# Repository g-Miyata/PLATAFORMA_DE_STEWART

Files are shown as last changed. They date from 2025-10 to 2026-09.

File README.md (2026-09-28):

[REACT__BADGE]: https://img.shields.io/badge/react-%2320232a.svg?style=for-the-badge&logo=react&logoColor=%2361DAFB
[TS__BADGE]: https://img.shields.io/badge/typescript-%23007ACC.svg?style=for-the-badge&logo=typescript&logoColor=white
[THREE__BADGE]: https://img.shields.io/badge/three.js-000000?style=for-the-badge&logo=threedotjs&logoColor=white
[FastAPI__BADGE]: https://img.shields.io/badge/FastAPI-005571?style=for-the-badge&logo=fastapi
[TailwindCSS__BADGE]: https://img.shields.io/badge/tailwindcss-%2338B2AC.svg?style=for-the-badge&logo=tailwind-css&logoColor=white

<div align="center">

logo ifsp

<hr/>

<h1 align="center" style="font-weight: bold;">PLATAFORMA DE STEWART</h1>







</div>

## Visão Geral

Este repositório reúne o projeto da Plataforma de Stewart do IFSP (TCC 2025):

- **interface web** em React + Three.js (`interface/web`), com modelo 3D da bancada, tema claro/escuro e acessibilidade;
- **backend** FastAPI (`interface/backend`), que calcula a cinemática e conversa com o ESP32 pela serial;
- **firmwares** do ESP32-S3 (`esp32s3_codes`).

O backend também tem um **dispositivo virtual (simulador)**: dá para usar toda a interface e validar movimentos sem hardware.

## Arquitetura

```mermaid
flowchart LR
    subgraph Web ["Interface web (React)"]
        P["Páginas: Atuadores · Cinemática · Joystick<br>Rotinas · IMU · Ganhos PID<br>Simulador de voo · Orientação do avião"]
        V["Modelo 3D (React Three Fiber)"]
    end

    subgraph Backend ["Backend FastAPI :8001"]
        R["REST: /calculate, /apply_pose, /pid/*,<br>/motion/*, /emergency-stop ..."]
        W["WebSocket /ws/telemetry"]
        S["SerialManager"]
    end

    SIM["Simulador<br>(simulated_device.py)"]
    FW["ESP32-S3<br>pid-control-filter-spike-bno.ino"]
    IMU["Transmissor IMU<br>BNO085 / MPU-6050"]
    FG["FlightGear + fg-bridge.py"]

    Web -->|HTTP / WS| Backend
    S -->|porta COM| FW
    S -->|porta SIMULADOR| SIM
    IMU -->|ESP-NOW| FW
    FG -->|HTTP| Backend
```

## Executando

### Pré-requisitos

- **Python 3.12** oficial para Windows ([python.org](https://www.python.org/downloads/windows/)). A 3.12.10 é a última 3.12 com instalador para Windows. Na instalação, marque _Add python.exe to PATH_.
  - Cuidado com Pythons embutidos em outros programas (por exemplo o do Inkscape), que criam o ambiente virtual num formato incompatível. O `start.bat` detecta e recusa esses casos.
- **Node.js não é necessário** para usar a bancada: o build da interface (`interface/web/dist`) vem pronto no repositório. Só é preciso Node 24 para desenvolver o frontend.

### Iniciar

Na raiz do projeto:

```bat
start.bat
```

O script:

1. procura o Python 3.12 (primeiro `py -3.12`, depois `python`);
2. cria o ambiente virtual em `interface/backend/.venv` e instala as dependências;
3. sobe o FastAPI em `http://localhost:8001`;
4. abre a interface em **http://localhost:8001/**.

| Endereço | Conteúdo |
| --- | --- |
| http://localhost:8001/ | Interface nova (React) |
| http://localhost:8001/antigo/ | Interface antiga (HTML/JS), mantida durante a migração |
| http://localhost:8001/docs | Documentação interativa da API |

> Se aparecer "O ambiente virtual existente é inválido", apague a pasta `interface/backend/.venv` e rode o `start.bat` de novo.

### Pelo celular (rede local)

No PC, abra a tela **Celular** (menu ou botão no cabeçalho) e clique em **Ligar o modo rede**: o backend passa a atender também em **HTTPS 8443** na rede, sem reiniciar, e a tela mostra o QR code, o endereço (`https://<IP-do-PC>:8443/celular`) e o **PIN**. Para já abrir ligado:

```bat
start.bat rede
```

- Com `start.bat rede`, o backend escuta na rede em **HTTP 8001** e **HTTPS 8443**, no mesmo processo (`interface/backend/serve.py`). O HTTPS usa um certificado autoassinado gerado na primeira vez em `interface/backend/certs/`, e é ele que libera o giroscópio do celular (os navegadores só dão o sensor em HTTPS).
- No celular, aceite uma vez o aviso de certificado e digite o PIN. **Um celular por vez:** com um já conectado, o PC mostra qual é (aparelho, IP, há quanto tempo) e o botão para desconectá-lo; um segundo celular vê o aviso e só entra depois. No celular, **Desconectar** (no topo) libera a vez. O PC também mostra quem abriu a página e está esperando o PIN, e pode gerar outro PIN.
- Sem o PIN, o celular só acompanha. O botão **PARAR** funciona sempre, em qualquer aparelho. O próprio PC nunca pede PIN. Um IP que erra o PIN 5 vezes fica bloqueado por um minuto.
- A tela `/celular` tem **giroscópio** (incline o celular e o tampo acompanha, com zerar, sensibilidade e iniciar/parar), **joystick na tela** (dois sticks, Z e yaw) e **Bancada 3D por toque** (P1–P6 ou tampo, − / + que repetem ao segurar, desfazer e ao vivo). O controle para sozinho se a tela apagar, se o sensor parar ou numa parada de emergência.
- **Firewall:** na primeira vez, o Windows pergunta se libera o Python; permita em **redes privadas**. Para liberar à mão, num prompt de administrador:
  `netsh advfirewall firewall add rule name="Plataforma de Stewart" dir=in action=allow protocol=TCP localport=8001,8443 profile=private`

## Modo simulação (sem hardware)

No topo da interface, escolha **Simulador** e clique em **Conectar**. O selo muda para **SIMULAÇÃO** (azul). Nada físico se move, e todas as páginas funcionam.

- O backend passa a usar `interface/backend/simulated_device.py` no lugar da porta serial. Ele aceita os mesmos comandos do firmware (`spmm6x=`, `sel=`, `kpmm=`, `A`/`R`/`OK`...), roda o mesmo PID e responde com a mesma telemetria CSV.
- A dinâmica de cada atuador (velocidade máxima e zona morta) foi ajustada aos ensaios de degrau reais (`MATLAB/workspace1-6.mat`) por `interface/backend/tools/fit_sim_params.py`, com fit de ~90%. Os parâmetros ficam em `interface/backend/sim_params.json`.
- No modelo 3D, a plataforma sólida é a medida (telemetria) e o **fantasma verde** é a pose comandada. A diferença entre as duas mostra o atraso real dos atuadores.
- A página **Rotinas** estima a velocidade de pico que cada movimento exige e avisa quando ela passa do que os atuadores sustentam (~12 mm/s).
- Nas páginas Joystick e IMU há controles virtuais (sliders) para quando não há gamepad ou sensor.
- A **Bancada 3D** (`/bancada-3d`) traz o modelo mais detalhado, com tela cheia. Clique num pistão e arraste a seta para mudar só o comprimento dele: os outros cinco ficam fixos e o tampo se acomoda pela cinemática direta. Clique no ponto verde do tampo para mover a plataforma inteira em Z, roll, pitch ou yaw. Tudo também funciona pelo teclado.

Para usar o hardware, selecione a porta COM do ESP32-S3 e confirme. O selo fica vermelho, **HARDWARE REAL**.

### Criar, ensinar e analisar

Além das páginas de controle, o menu tem:

| Página | O que faz |
| --- | --- |
| **Gravar e reproduzir** (`/gravar`) | Tudo na própria página: **ponto a ponto** (posicione a plataforma na Bancada 3D embutida ou pelos valores e grave o ponto; a rotina liga os pontos) ou **ao vivo** (dirija com os joysticks da tela ou um gamepad e grave o movimento). Vira poses-chave numa linha do tempo com interpolação suave, prévia no modelo e reprodução na plataforma (`POST /motion/trajectory`, 60 Hz). Confere curso e velocidade antes de mover. |
| **Programação em blocos** (`/blocos`) | Blocos no estilo Scratch (Blockly): mover para, mover eixo, esperar, repetir, rotinas prontas. O programa vira uma trajetória, com a lista de passos em texto. |
| **Apresentação** (`/apresentacao`) | Tela para feiras e exposições, em página inteira (tema escuro ou claro, pelo botão no canto). Mostra um show automático de 6 cenas (título, 6 graus de liberdade, pistões ao vivo, simulador de voo, cinemática) e quem toca na tela ou mexe no gamepad assume o controle, voltando ao show após 30 s. A bancada física só se move pelo **painel do operador** (tecla **O** ou segurar o logo): quiosque com amplitude e velocidade limitadas, controle do público na bancada (até 5°) e tempo de sessão. No painel também dá para trocar o show pelo **Simulador de voo**: um voo gravado do ERJ145 toca em laço pelo motion cueing (washout), com instrumentos na tela, a imagem do FlightGear no canto quando ele está aberto e, se o operador ligar, a bancada engatada no cueing. `?cena=voo` abre direto numa cena e `?modo=voo` no simulador de voo. |
| **Aula de cinemática** (`/aula`) | Curso em dois módulos, na notação do TCC (aᵢ, bᵢ, p, R, Lᵢ = ‖p + R·bᵢ − aᵢ‖). **Conhecendo a Plataforma**: peças, história, 6 GDL, atuadores e juntas, referenciais {B} e {P}. **Cinemática**: seriais × paralelos com um braço UR5e (cadeia DH e as até 8 soluções da inversa) e um braço 2R, pose e matrizes com números ao vivo, inversa passo a passo e direta com experimento, esferas de restrição e as iterações do solver. Tem perguntas rápidas e o progresso fica salvo. **Modo aula** (tecla F): tela cheia para projetar, com texto e modelo maiores; ←/→ passam as etapas. |
| **Jogo da bolinha** (`/jogo`) | Incline o tampo e leve a bolinha ao alvo, em 5 fases. Pode espelhar na plataforma (até 5°, devagar). |
| **Espaço de trabalho** (`/espaco-de-trabalho`) | Volume que o centro do tampo alcança com os limites reais, corte colorido pelo limite que está mais perto (curso, cardã da base, cardã do tampo ou folga entre pernas), inclinação máxima por direção e alcance de cada eixo com e sem margem. |
| **Limites da mecânica** (Ajustes → `/limites`) | Os valores físicos de `interface/backend/limits.json` (curso de 500 a 750 mm, ângulo máximo dos cardãs, raio e folga das pernas) e a margem de operação (20%), com o alcance que resulta. Tudo o que comanda a bancada deriva daqui. |
| **Laboratório: calço do cardã** (`/laboratorio/calco`, fora do menu) | Simula um calço inclinado embaixo de cada cardã do tampo: compara o alcance com a montagem de hoje, testa poses, mostra a peça em 3D e baixa o STL do calço e da arruela inclinada, com o passo a passo de montagem. É só simulação: não muda os limites da bancada. |
| **Calibração** (Ajustes → `/calibracao`) | Um processo de 3 a 4 min que interrompe o que estiver rodando e faz o **autoteste** (cada pistão sozinho ±30 mm em torno do home: velocidade, atraso, erro final e ruído; aponta travado, invertido, lento ou ruidoso) e a **recalibração** do simulador (gêmeo digital: um simulador "sombra" recebe os mesmos comandos só durante a calibração; o ajuste de vmax e zona morta só entra se melhorar a reprodução). Gera um relatório datado, comparado com o anterior; os parâmetros novos vão para o `sim_params.json` (com cópia `.bak`) só se você aplicar. Também compara ensaios CSV das Rotinas com o simulador. |
| **Simulador de voo** (`/simulador-voo`) | Sensações do voo no FlightGear com washout clássico (inclinação sustentada, translação e rotação), respeitando curso e velocidade dos pistões, com o ERJ145 do IFSP voando no FlightGear dentro da página. Toca voos gravados (inclui uma rotina pronta), grava voos ao vivo via UDP e compara avião × plataforma. Veja [MOTION-CUEING-README.md](MOTION-CUEING-README.md) e [FLIGHTGEAR-SETUP.md](FLIGHTGEAR-SETUP.md). |
| **Orientação do avião** (`/orientacao-voo`) | A plataforma copia roll e pitch do avião (até ±12°), ao vivo ou de um voo gravado, com o mesmo FlightGear embutido. |

Enquanto uma rotina ou trajetória roda, o backend recusa comandos manuais (409), para que eles não briguem com o movimento. Durante a calibração, recusa qualquer comando (poses, rotinas, PID, console).

### Segurança

- **Parar** (ou a tecla **Esc**) chama `POST /emergency-stop`: interrompe rotinas e a simulação de voo, tira o firmware do modo manual (`OK`) e congela os atuadores na posição atual. Joystick, IMU e "aplicar automaticamente" desligam sozinhos.
- **Limites reais** (`interface/backend/limits.py`, igual no frontend em `lib/limits.ts`): uma pose só é aceita se, com **20% de margem**, cada perna ficar no curso (525 a 725 mm dos 500 a 750 mm do atuador), os cardãs da base e do tampo não passarem de 80% do ângulo máximo e duas pernas não chegarem perto demais. O ângulo máximo dos cardãs (45°) é de catálogo: a junta real (o cardã metálico no topo e na base de cada perna, preso ao suporte azul impresso) não foi medida (o modelo 3D do cardã daria só 17°, menos do que a bancada já faz; veja `tools/estimate_cardan_limit.py`). Meça e ajuste em **Ajustes → Limites da mecânica**. O home fica no meio do curso de operação (570 mm). Sliders, joystick, IMU, rotinas, trajetórias, setpoints manuais e o simulador de voo usam esse envelope, em vez de faixas fixas.
- O backend escuta só em `127.0.0.1`, e o CORS é restrito ao próprio servidor e ao servidor de desenvolvimento. No modo rede (`start.bat rede`), escuta na rede e exige o PIN para comandos que vêm de outros aparelhos.

## Desenvolvimento

### Backend

```bat
cd interface\backend
.venv\Scripts\activate
pip install -r requirements.txt pytest
uvicorn app:app --reload --port 8001
pytest
```

Os testes automatizados ficam em `interface/backend/tests/` e cobrem a cinemática, o simulador e a API com o simulador conectado. Os `test_*.py` soltos na pasta do backend são scripts manuais antigos (precisam de servidor ou hardware) e o `pytest.ini` os ignora.

### Frontend (`interface/web`)

```bat
cd interface\web
npm install
npm run dev
```

O servidor de desenvolvimento fica em http://localhost:5173 e repassa a API para o backend em `:8001`.

| Comando | O que faz |
| --- | --- |
| `npm run build` | Gera `dist/`, que o FastAPI serve. **Rode antes de commitar** mudanças no frontend. |
| `npm run lint` / `npm run typecheck` | ESLint (inclui regras de acessibilidade jsx-a11y) e TypeScript |
| `npm test` | Testes unitários (Vitest) |
| `npm run test:e2e` | Playwright + axe contra o build, com o simulador (usa o Edge instalado no Windows)  |

Detalhes de arquitetura, tema IFSP, acessibilidade e o fluxo para melhorar o modelo 3D no Blender estão em [interface/web/README.md](interface/web/README.md).

### Integração contínua

`.github/workflows/ci.yml` roda pytest, lint, tipos, testes, build e os testes de ponta a ponta com acessibilidade em cada PR. Em tags `v*`, anexa o build (`stewart-web-dist.zip`) à release.

### Firmware ESP32-S3

- **Arduino IDE 2.x**, com o core _esp32 by Espressif Systems_ **2.0.x** (testado na 2.0.15). O core 3.x muda `ledcSetup`/`ledcAttachPin` e o callback do ESP-NOW, e o código não compila nele.
- **Bibliotecas:** SparkFun BNO08x Cortex Based IMU 1.0.6 e MPU6050_light.
- **Driver USB-serial:** CP210x ([tutorial Robocore](https://www.robocore.net/tutoriais/instalando-driver-do-nodemcu)).

| Sketch | Função |
| --- | --- |
| `esp32s3_codes/stewart-platform-control/pid-control-filter-spike-bno/` | Firmware principal: PID dos 6 atuadores, telemetria, receptor ESP-NOW |
| `esp32s3_codes/stewart-platform-control/BNO085/` | Transmissor de orientação com BNO085 |
| `esp32s3_codes/stewart-platform-control/mpu-6050/` | Transmissor de orientação com MPU-6050 |
| `esp32s3_codes/others/` | Sketches de teste antigos (algumas pinagens diferem da principal: não gravar sem conferir) |

Comandos seriais e telemetria: [PID-CONTROL-FILTER-SPIKE-BNO.md](PID-CONTROL-FILTER-SPIKE-BNO.md).

## Estrutura do repositório

| Pasta | Conteúdo |
| --- | --- |
| `interface/web` | Interface React (código em `src/`, build em `dist/`) |
| `interface/backend` | FastAPI, simulador, testes (`tests/`) e ferramentas (`tools/`) |
| `interface/frontend` | Interface antiga (servida em `/antigo/` até o fim da migração) |
| `interface/simulation` | Ponte FlightGear (`fg-bridge.py`), motion cueing e voos gravados |
| `interface/mcp-flightgear`  | Servidor MCP para ler e controlar o FlightGear pelo Claude |
| `interface-coleta-de-dados` | Aplicativos Python usados nas aquisições do TCC |
| `esp32s3_codes` | Firmwares do ESP32-S3 |
| `MATLAB` | Identificação de sistema e projeto dos controladores |
| `aquisições` | Dados brutos dos ensaios (CSV) por pistão |
| `3D-drawings-archives` | Peças para impressão 3D (STL/3MF) |
| `docs` | Monografia, apresentação e cópias em PDF da documentação |

## Documentação por módulo

Os documentos abaixo descrevem a **interface antiga** (em `/antigo/`) e os endpoints, que continuam os mesmos:

- [JOYSTICK-CONTROL-README.md](JOYSTICK-CONTROL-README.md) e [CONTROLLER-README.md](CONTROLLER-README.md): joystick e `/joystick/pose`
- [KINEMATICS-README.md](KINEMATICS-README.md): cinemática, `/calculate` e `/apply_pose`
- [ACCELEROMETER-README.md](ACCELEROMETER-README.md): controle por IMU e `/mpu/control`
- [ROUTINES-README.md](ROUTINES-README.md): rotinas e `/motion/*`
- [ACTUATORS-README.md](ACTUATORS-README.md): telemetria, setpoints e comandos manuais
- [SETTINGS-README.md](SETTINGS-README.md): `/pid/gains` e `/pid/settings`
- [FLIGHTGEAR-README.md](FLIGHTGEAR-README.md): ponte antiga roll/pitch via Telnet (interface `/antigo`)
- [interface/mcp-flightgear/README.md](interface/mcp-flightgear/README.md): servidor MCP do FlightGear
- [MOTION-CUEING-README.md](MOTION-CUEING-README.md): Simulador de voo e Orientação do avião, voos gravados e ponte UDP
- [FLIGHTGEAR-SETUP.md](FLIGHTGEAR-SETUP.md): instalar FlightGear, FGData e ERJ145, rodar no FlightGear e erros comuns
- Firmware: [PID-CONTROL-FILTER-SPIKE-BNO.md](PID-CONTROL-FILTER-SPIKE-BNO.md), [BNO085-README.md](BNO085-README.md), [MPU6050-README.md](MPU6050-README.md)

## Versionamento

A branch padrão é `main`. Use uma branch por mudança (`feat/...`, `fix/...`, `docs/...`) e abra um Pull Request: o CI precisa passar antes do merge.

### Autor

**Guilherme Miyata** - Instituto Federal de São Paulo (IFSP)
Trabalho de Conclusão de Curso - 2025

---

<a href='https://github.com/g-Miyata'>Github</a><br>
<a href='https://www.linkedin.com/in/g-miyata'>Linkedin</a><br>
<a href='https://www.g-miyata.com'>Portfólio</a>

**Última atualização:** Setembro 2026

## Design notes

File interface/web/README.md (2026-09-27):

# Interface web (React)

Frontend da Plataforma de Stewart: React 19 + TypeScript + Vite, Tailwind CSS v4, Radix UI, React Three Fiber (three.js) e Chart.js. O build (`dist/`) é servido pelo próprio FastAPI em `http://localhost:8001/`; não há dependência de CDN, então a interface funciona offline.

## Rodando

```bat
npm install
npm run dev        :: http://localhost:5173 (a API é repassada para o backend em :8001)
npm run build      :: gera dist/, servido pelo FastAPI. Rode antes de commitar.
npm run lint       :: ESLint + regras de acessibilidade (jsx-a11y) + regras do React Compiler
npm run typecheck
npm test           :: Vitest (cinemática, rotinas, joystick, CSV...)
npm run test:e2e   :: Playwright + axe contra o build, com o simulador
```

Equações em **KaTeX** (empacotado, funciona offline; `components/Tex.tsx`).

**Limites reais:** `lib/limits.ts` faz as mesmas checagens do backend (curso de operação, cardãs e folga entre pernas); `limits.test.ts` confere contra `limits.fixture.json`, gerado por `interface/backend/tools/make_limits_fixture.py` (rode de novo se mudar `limits.py`). `useLimits()` dá o alcance de cada eixo para sliders e controles.

O `test:e2e` usa o Edge instalado no Windows. Com o `start.bat` aberto, rode num backend separado (`PW_PORT=8011`) para não desconectar a sua sessão. Defina `PYTHON` com o Python do venv do backend se ele não for o `python` do PATH. No CI (Linux), use `PW_CHANNEL=chromium` depois de `npx playwright install chromium`.

## Estrutura

```
src/
  app/          App (rotas), AppShell (cabeçalho, menu, selo de modo), providers, nav
  components/   ui/ (Button, Card, campos, status), charts/LiveChart, PageLayout (PageHeader, WithViewer)
  features/
    platform3d/ modelo 3D: PlatformViewer, Scene, Actuators, TopPlate, BaseFrame, GhostPlatform,
                BlueMount (STL real), ModelSlot (modelos .glb do Blender), sceneState (SceneStore)
    control/    PoseEditor, validação no backend, trava de controle ao vivo
    serial/     conexão (hardware real pede confirmação; padrão = simulador)
    safety/     parada de emergência (botão e tecla Esc)
    bench3d/    Bancada 3D: store de edição (FK ao mexer num pistão, IK ao mexer na pose),
                gizmos de arraste (seta de eixo, anéis de rotação) e cena premium
    joystick/   Gamepad API + mapeamento idêntico ao /joystick/pose
    routines/   presets, estimativa de velocidade, status e gráfico comandado × medido
    recorder/   trajetórias (interpolação, simplificação, viabilidade), gravador global e biblioteca
    blocks/     blocos do Blockly e compilador (JSON do Blockly → poses-chave)
    presentation/ tela de exposição: laço de cenas, palco (bloom, reflexo), controle do público,
                painel do operador e quiosque (lista segura de movimentos)
    lesson/     aula: currículo (curriculum.ts), widgets, sobreposições 3D e o UR5e (serial/)
    game/       física da bolinha (passo fixo de 120 Hz), fases e cena
    workspace/  varredura do espaço de trabalho (Web Worker) e iso-superfície
    calibration/ calibração (status, indicador no cabeçalho, relatório)
    twin/       gêmeo digital: gráfico real × simulado, métricas e comparação de ensaio CSV
    actuators/  console serial
  lib/          api (REST tipado), ws (WebSocket único com backoff), kinematics (inversa),
                forwardKinematics (direta, Levenberg-Marquardt), types, csv
  stores/       zustand: connection, telemetry, ui (tema, contador de parada de emergência)
  pages/        uma página por rota
```

### Fluxo de dados

- **Um WebSocket só** (`lib/ws.ts`), aberto na raiz do app. Como é uma SPA, ele sobrevive à troca de páginas. As mensagens vão para `stores/telemetry.ts` (`telemetry`, `motion_tick`, `raw`).
- **REST** em `lib/api.ts`, sempre na mesma origem. O estado da serial é consultado a cada 2 s (`features/serial/status.ts`) e alimenta o selo **SIMULAÇÃO / HARDWARE REAL / DESCONECTADO / BACKEND OFFLINE**.
- **Dados de alta frequência não passam pelo React**: gráficos (`LiveChart`) e o 3D (`SceneStore`) assinam o store diretamente e se atualizam de forma imperativa. Tabelas e textos usam `useThrottledTelemetry` (5 a 10 Hz).
- **Cinemática no navegador serve só para desenhar** (`lib/kinematics.ts`, mesmas fórmulas de `app.py`, com teste contra valores gerados pelo backend). Validar e aplicar uma pose é sempre papel do backend.

### Modelo 3D

`PlatformViewer` mostra duas plataformas:

- **sólida**: a pose medida (`pose_live` da telemetria; com o simulador, é o modelo virtual). Sem telemetria, mostra a pose prevista.
- **fantasma verde**: a pose comandada/prevista pela página (sliders, joystick, IMU, rotina). Só aparece quando difere da medida.

Cada atuador acende em âmbar perto do batente e em vermelho fora do curso. As mesmas informações estão na tabela abaixo do canvas, que é a alternativa textual do 3D. O eixo Z aponta para cima e as unidades são mm, iguais às do backend.

Tudo é montado a partir da geometria do `GET /config` (`base_points`, `platform_points_local`, curso), com fallback embutido em `features/platform3d/geometry.ts`. Mudou a geometria no backend, o desenho acompanha.

### Bancada 3D

O modelo "premium" (`features/platform3d/premium/`) é usado só nesta tela:

- **Peças:** tubo de alumínio de cantos arredondados, motor com etiqueta e o número do pistão, caixa de redução, juntas cardã cromadas, perfis 40×40 com canais em T e a parte elétrica (fonte, drivers, canaletas, trilho DIN, botão de emergência).
- **Render:** pós-processamento (N8AO, bloom, AgX, SMAA) no modo **Alta**. O modo **Leve** entra sozinho se o FPS cair.
- **Frameloop sob demanda:** a cena só redesenha quando a edição, a telemetria ou a câmera mudam.

**Teclado** (com o modelo em foco):

| Tecla | Ação |
| --- | --- |
| 1 a 6 | seleciona um pistão |
| C | seleciona o tampo e alterna o eixo |
| Z, R, P, Y | escolhe altura, roll, pitch ou yaw |
| setas | ajustam (Shift ×10) |
| Ctrl+Z | desfaz |
| F | tela cheia |

## Tema IFSP e acessibilidade

- **Tokens** em `src/index.css`, para `[data-theme="light"]` e `[data-theme="dark"]`. O verde (#2F9E41) e o vermelho (#CD191E) institucionais são usados em ícones, bordas e superfícies. Para texto, o tema claro usa um verde escurecido (#1B6E2B) e o escuro um verde claro, para passar o contraste AA.
- **Escolha do tema:** o padrão segue o sistema; o botão no cabeçalho alterna e salva em `localStorage`. Um script inline em `index.html` aplica o tema antes da primeira pintura.
- **Meta: WCAG 2.1 AA.** O `npm run test:e2e` roda o axe em todas as páginas, nos dois temas, e falha em violações sérias ou críticas.
- **Regras seguidas nos componentes:**
  - todo controle tem rótulo;
  - sliders com `aria-valuetext` em pt-BR ("5,5 graus") e campo numérico ao lado;
  - estado nunca só por cor (ícone + texto);
  - link "Pular para o conteúdo";
  - o foco vai para o conteúdo ao trocar de página;
  - atalho **Esc** para a parada de emergência;
  - `prefers-reduced-motion` desliga animações e a suavização do 3D.

## Modelos 3D (Blender)

A carcaça dos atuadores, os cardãs e a parte elétrica da bandeja (drivers, fonte, disjuntor, réguas de bornes, DB37 e botoeira de emergência) vêm de `.glb` gerados por scripts do Blender em [`3D-drawings-archives/blender/`](../../3D-drawings-archives/blender/README.md). O braço UR5e da aula vem do MuJoCo Menagerie (BSD-3-Clause, licença em `public/models/serial/LICENSE-ur5e.txt`), convertido por `ur5e.py`. O resto é gerado no código (procedural), com proporções tiradas das fotos da bancada. O bloco azul da base usa a peça real do repositório (`3D-drawings-archives/kardan-joint/kardan-joint.stl`, copiada para `public/models/`).

Para trocar uma peça por um modelo mais detalhado feito no Blender:

1. **Unidades:** em *Scene Properties > Units*, use *Unit Scale* 0,001 e *Length* em milímetros, para que **1 unidade = 1 mm**.
2. **Eixos e origem** (o exportador glTF converte o Z do Blender no +Y do three.js, que é o eixo do atuador no código):

   | Nome do arquivo | Origem (0,0,0) | Eixo do Blender +Z | +X |
   | --- | --- | --- | --- |
   | `actuator-housing.glb` | centro da junta da base | ao longo do atuador; a carcaça vai de ~32 a ~330 mm | lado do motor (para fora da plataforma) |
   | `actuator-rod.glb` | centro da haste | ao longo da haste (400 mm de comprimento) | livre |
   | `kardan-top.glb` | centro da junta superior | ao longo da perna | livre |

3. **Materiais:** Principled BSDF (vira PBR no glTF). Alumínio fosco, cromo para a haste, texturas de até 1024 px. Não é preciso pintar a cor de cada pistão: a faixa colorida continua sendo desenhada pelo código.
4. **Exportar:** *File > Export > glTF 2.0*, formato **.glb**, *Selected Objects*, *+Y Up* ligado, *Apply Modifiers*, sem câmeras, luzes ou animações.
5. **Otimizar** (Meshopt; não use Draco, que precisaria de CDN):

   ```bat
   npx @gltf-transform/cli optimize actuator-housing.glb public/models/actuator-housing.glb --compress meshopt --texture-compress webp
   ```

6. **Registrar** o nome em `public/models/manifest.json` (ex.: `"models": ["actuator-housing"]`) e rodar `npm run build`.

Se o arquivo faltar ou não carregar, a peça procedural volta sozinha (`ModelSlot`). Para conferir a escala, a carcaça precisa ter ~330 unidades no eixo do atuador. Se vier 0,33, a unidade estava em metros.

**Referências visuais:** fotos da bancada e Figuras 17, 20, 21 e 27 da monografia (`docs/TCC_Guilherme_rev4_final.docx`).

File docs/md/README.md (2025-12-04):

[JAVASCRIPT__BADGE]: https://img.shields.io/badge/JavaScript-000?style=for-the-badge&logo=javascript
[CSS3__BADGE]: https://img.shields.io/badge/CSS3-%231572B6.svg?style=for-the-badge&logo=css3&logoColor=white
[FastAPI__BADGE]: https://img.shields.io/badge/FastAPI-005571?style=for-the-badge&logo=fastapi
[TailwindCSS__BADGE]: https://img.shields.io/badge/tailwindcss-%2338B2AC.svg?style=for-the-badge&logo=tailwind-css&logoColor=white
[HTML5__BADGE]: https://img.shields.io/badge/html5-%23E34F26.svg?style=for-the-badge&logo=html5&logoColor=white

<div align="center">

logo ifsp

<hr/>

<h1 align="center" style="font-weight: bold;">PLATAFORMA DE STEWART</h1>







</div>

## Visão Geral

Esta documentação consolida o ecossistema do projeto da Plataforma de Stewart (IFSP – TCC 2025), abrangendo o **frontend** (interfaces web em Three.js/Vanilla), o **backend** (FastAPI + Serial) e os **firmwares** do ESP32-S3. Abaixo você encontrará uma visão macro dos módulos, instruções de instalação/execução e um guia de versionamento, além de links para documentação detalhada de cada funcionalidade.

## Arquitetura Macro

```mermaid

flowchart TB
    subgraph Frontend ["FRONTEND"]
        F1[controller.html] --> F2[joystick.html] --> F3[kinematics.html] --> F4[accelerometer.html] --> F5[routines.html] --> F6[actuators.html] --> F7[settings.html]
    end

    subgraph Backend ["BACKEND"]
        B1["Endpoints REST<br>/apply_pose, /calculate,<br>/pid/*, /motion/*"]
        B2["WebSocket /ws/telemetry"]
        B3["Serial Manager<br>(pyserial)"]
    end

    subgraph Firmware ["ESP32-S3"]
        FW1["PID controle 6 DOF<br>pid-control-filter-spike-bno.ino"]
        FW2["Transmissor BNO085<br>BNO085.ino"]
        FW3["Transmissor MPU6050<br>cmpu-6050.ino"]
    end

    IMU["IMU remota<br>(BNO085 OU MPU6050)"]

    Frontend -->|HTTP/WS| Backend
    Backend -->|Serial USB| FW1
    FW1 --> Backend

    FW2 --> IMU
    FW3 --> IMU
    IMU -->|ESP-NOW| FW1

```

# Iniciando

## Instalação

### Pré-requisitos

#### Versão do Python

- Python **3.12.17**

#### Dependências Python

As bibliotecas do backend estão em `interface/backend/requirements.txt`. Instale-as com:

```bash
pip install -r requirements.txt
```

Conteúdo atual:

```
# ==== API e servidor Web  ====
fastapi==0.104.1
starlette==0.27.0
uvicorn[standard]==0.24.0.post1
pydantic==2.5.3
python-multipart==0.0.9

# ==== Científico ====
numpy==1.26.4
scipy==1.13.1

# ==== Serial ====
pyserial==3.5

# ==== Utilitários ====
python-dotenv==1.0.1
typing-extensions>=4.8,<5
```

#### Ambiente ESP32-S3/ESP32

- **Arduino IDE 2.x**
- **Core ESP32**: _esp32 by Espressif Systems_ v2.0.15
- **Bibliotecas adicionais**:
  - SparkFun BNO08x Cortex Based IMU – v1.0.6
- **Driver USB–Serial**: CP210x USB to UART Bridge  
  Download e instruções: [Robocore – Instalando driver do NodeMCU](https://www.robocore.net/tutoriais/instalando-driver-do-nodemcu)

#### Outros

- **Node.js** LTS (para rodar servers estáticos, bundlers opcionais etc.).
- **Ferramentas de linha de comando**: `git`, `make` (opcional), `python -m http.server` ou similar para servir o frontend.

### Backend (FastAPI)

1. Entre em `interface/backend`.
2. Crie (opcional) um ambiente virtual e instale dependências:
   ```bash
   python -m venv .venv
   source .venv/bin/activate  # Linux/macOS
   .\.venv\Scripts\activate   # Windows PowerShell
   pip install -r requirements.txt
   ```
3. Execute o servidor:
   ```bash
   uvicorn app:app --reload --host 0.0.0.0 --port 8001
   ```
4. Confirme que a API responde em `http://localhost:8001/docs`.

### Frontend

O frontend é estático. Basta abrir os arquivos `.html` diretamente no navegador ou servir via um servidor local (ex.: `live-server`, `python -m http.server`, etc.). Para páginas que dependem de módulos ES6, verifique se o navegador carrega via `file://` sem bloquear. Recomenda-se rodar um server simples:

```bash
cd interface/frontend
python -m http.server 8080
# Abrir http://localhost:8080/controller.html
```

> Existe também um script pronto (`start.bat`) na raiz do repositório. Ele abre duas janelas de terminal: uma com o backend FastAPI (`uvicorn`) e outra com `python -m http.server 8080` para o frontend. Basta executar `start.bat` para subir ambos.

### Firmware ESP32-S3

1. Abra `esp32s3_codes/pid-control-filter-spike-bno/pid-control-filter-spike-bno.ino` (ou variantes) no Arduino IDE (ESP32 S3 board selecionada) ou PlatformIO.
2. Ajuste as constantes de pinagem/ganhos conforme necessário.
3. Compile e faça upload via USB.

> Consulte [PID-CONTROL-FILTER-SPIKE-BNO.md](PID-CONTROL-FILTER-SPIKE-BNO.md) para detalhes completos do firmware.

## Execução e Fluxo

1. **Ligar o ESP32-S3** com o firmware PID. Ele aguardará setpoints pela serial e telemetria pelo sensor.
2. **Iniciar o backend** (`uvicorn app:app --reload --port 8001`).
3. **Abrir uma página do frontend**:
   - `joystick.html` para controle via joystick.
   - `kinematics.html` para cálculos de cinemática.
   - `accelerometer.html` para controle por IMU.
   - `routines.html` para rotinas de movimentoBN e gráficos.
   - `actuators.html` para controle PID e telemetria.
   - `settings.html` para ajustes rápidos de ganhos/offsets.
4. Conectar-se à porta serial na UI e ativar as funcionalidades desejadas.

## Documentação por Módulo

- **Controle por Joystick (controller/joystick)**  
  [JOYSTICK-CONTROL-README.md](JOYSTICK-CONTROL-README.md) – explica endpoints (`/joystick/pose`), mapeamentos dos eixos, telemetria, segurança e UI.
- **Cinemática (kinematics.html + kinematics.js)**  
  [KINEMATICS-README.md](KINEMATICS-README.md) – descreve o preview 3D, inputs e integração com `/calculate` e `/apply_pose`.
- **Controle por Acelerômetro**  
  [ACCELEROMETER-README.md](ACCELEROMETER-README.md) – modo roll/pitch/yaw via IMU (MPU/BNO), WebSocket de telemetria, recalibração e comandos `/mpu/control`.
- **Rotinas de Movimento**  
  [ROUTINES-README.md](ROUTINES-README.md) – presets, Chart.js, IndexedDB para gravação, endpoints `/motion/*`.
- **Painel de Atuadores / PID**  
  [ACTUATORS-README.md](ACTUATORS-README.md) – telemetria, setpoints, comandos manuais, export CSV, integração com `/pid/*`.
- **Painel de Configurações**  
  [SETTINGS-README.md](SETTINGS-README.md) - explica como ler/aplicar `kp/ki/kd`, deadband, PWM mínimo via `/pid/gains` e `/pid/settings`.
- **Integração FlightGear**  
  [FLIGHTGEAR-README.md](FLIGHTGEAR-README.md) - ponte Telnet->FastAPI que lê roll/pitch do simulador, valida com `/calculate`, publica pré-visualização e envia poses seguras via `/apply_pose`.
- **Firmware ESP32-S3**
  - [PID-CONTROL-FILTER-SPIKE-BNO.md](PID-CONTROL-FILTER-SPIKE-BNO.md) – loop PID principal no ESP32-S3.
  - [BNO085-README.md](BNO085-README.md) – transmissor ESP-NOW baseado no sensor SparkFun BNO08x (Euler + quaternions).
  - [MPU6050-README.md](MPU6050-README.md) – transmissor ESP-NOW com MPU-6050 (roll/pitch/yaw simples).

## Código do ESP32-S3

O código principal está em `esp32s3_codes/pid-control-filter-spike-bno/`. Ele implementa:

- **ESP-NOW** para receber dados do sensor de orientação (MPU6050 ou BNO085) e gravar MAC para comandos de retorno.
- **Controle PID** com feedforward e anti-windup.
- **Parser serial** para receber setpoints e ajustes vindos do backend (comandos `spmm6x`, `kpmm`, `u0a`, `offset`, etc.).
- **Telemetria** no formato CSV, compatível com gráficos no frontend (`actuators.html`).

> Transmissores auxiliares:
>
> - [BNO085-README.md](BNO085-README.md) - leitura do SparkFun BNO08x (Euler + quaternions) e envio por ESP-NOW.
> - [MPU6050-README.md](MPU6050-README.md) - versão simplificada usando MPU6050_light.

### Principais integrações com o backend

- `apply_setpoint_all` e `apply_setpoint_individual` são acionados via `/apply_pose` (controller/joystick).
- `set_pid_gains`, `set_pid_offset`, `set_pid_feedforward` são usados pelas páginas `settings` e `actuators`.
- Comandos manuais (`man=adv`, `man=ret`, `man=free`) são expostos no painel de atuadores para testes de bancada.

## Versionamento

O repositório utiliza Git (branch padrão `docs/atualiza-documentacao`). Recomenda-se o seguinte fluxo:

1. **Commits frequentes** por feature:
   - `feature/frontend-joystick-z-trigger`
   - `feature/backend-motion-endpoints`
   - `docs/add-accelerometer-readme`
2. **Pull Requests** para revisão (incluir referência a issues do Trello/Jira).
3. **Tags** para releases estáveis:
   - `v1.0.0` – primeiro release funcional (controle manual + PID).
   - `v1.1.0` – inclui modos de rotinas, telemetria e joystick Z-trigger.
4. **Changelogs** no README ou em `CHANGELOG.md`.

### Autor

**Guilherme Miyata** - Instituto Federal de São Paulo (IFSP)  
Trabalho de Conclusão de Curso - 2025

---

<a href='https://github.com/g-Miyata'>Github</a><br>
<a href='www.linkedin.com/in/g-miyata'>Linkedin</a><br>
<a href='https://www.g-miyata.com'>Portfólio</a>

**Última atualização:** Novembro 2025

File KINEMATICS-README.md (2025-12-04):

# Sistema de Cinemática & Telemetria - Plataforma de Stewart

## Visão Geral

Interface completa para montar poses, visualizar o resultado em 3D e acompanhar a plataforma física em tempo real. A página `kinematics.html`, apoiada pelo script `kinematics.js`, conversa com o backend FastAPI (`app.py`) para calcular cinemática inversa, validar limites e enviar comandos via serial.

## Características

- Controle manual da pose com inputs numéricos e sliders sincronizados para X/Y/Z (±60 mm, Z 400–600 mm) e Roll/Pitch/Yaw (±25°).
- Pré-visualização 3D instantânea no `canvas-preview`, renderizada a partir da resposta do endpoint `/calculate`.
- Painel live (`canvas-live`) que replica a pose real recebida por WebSocket e mostra o comprimento de cada atuador.
- Monitoramento do IMU/MPU com leitura de Roll, Pitch, Yaw e quaternion formatado quando enviado pelo BNO085.
- Botão “Aplicar na Bancada” condicionado à validade do cálculo; dispara `/apply_pose` e envia `spmm6x=...` para o ESP32.
- Ações auxiliares: reset rápido, recalibração do MPU, indicadores de erro/toast e watchdog para telemetria.

## Arquitetura

### Backend (`interface/backend/app.py`)

- **`POST /calculate`**: recebe `PoseInput`, executa `platform.inverse_kinematics`, calcula percentuais de curso e devolve `PlatformResponse` com `actuators`, `base_points`, `platform_points` e flag `valid`.
- **`POST /apply_pose`**: reaproveita a pose calculada, verifica novamente a validade, converte para curso com `lengths_to_stroke_mm` e envia `spmm6x` via `SerialManager`. Retorna `{ applied, valid, setpoints_mm }`.
- **`POST /serial/send`**: usado para enviar comandos diretos como `{"command": "recalibra"}` quando o usuário solicita recalibração do MPU.
- **`GET /serial/status`**: informa se já existe porta conectada, permitindo que o frontend inicialize `serialConnected` ao carregar.
- **WebSocket `/ws/telemetry`**: transmite eventos `motion_tick` (com `pose_cmd`) e pacotes de telemetria normalizados usados no canvas live.

### Frontend (`interface/frontend/scripts/kinematics.js`)

- Inicializa componentes compartilhados via `initCommonSerialControls` e carrega o menu (`nav-menu.js`).
- Expõe funções globais: `setupInputSync`, `getPoseFromUI`, `calculatePosition`, `applyToBench`, `resetPosition`, `recalibrateMPU`, `updatePreviewMeasures`, `updateLiveMeasures`, `updateMPUData`, `initLocalTelemetryWS`.
- Depende de utilitários:
  - `draw3DPlatform` (de `three-utils.js`) para desenhar base/plataforma/atuadores.
  - `normalizeTelemetry` e `applyLiveTelemetry` (de `telemetry-utils.js`) para tratar o feed live.
  - `showToast`, `setSerialStatus`, `serialConnected`, `serialPorts` (de `common.js`) para UX, conexão e estado global.

## Painéis de `kinematics.html`

1. **Status da Porta Serial** (`connection-status`): LED e texto atualizados conforme `serialConnected`/porta ativa.
2. **Painel do Acelerômetro** (`mpu-data-section`): botão “Recalibrar”, valores de Roll/Pitch/Yaw com duas casas e quaternion formatado (`q = a + bi + cj + dk`).
3. **Controles de Pose**: inputs `x-pos`, `y-pos`, `z-pos`, `roll`, `pitch`, `yaw` sincronizados aos sliders; botões “Calcular Posição”, “Resetar” e “Aplicar na Bancada”.
4. **Medidas dos Atuadores**: blocos `preview-piston-*` (resultado do cálculo) e `live-piston-*` (telemetria), coloridos em verde quando válidos e vermelho quando fora do limite.
5. **Visualização 3D**: `canvas-preview` (resposta do cálculo) e `canvas-live` (telemetria) renderizados pelo Three.js.

## Fluxo de Funcionamento

1. Usuário ajusta sliders/inputs → `getPoseFromUI` monta o payload.
2. `calculatePosition` envia `POST /calculate`, exibe indicador de loading e trata mensagem de erro/sucesso.
3. Com resposta válida, salva `currentPlatformData`, atualiza medidas (`updatePreviewMeasures`) e renderiza `canvas-preview` com `draw3DPlatform`; o botão “Aplicar na Bancada” é exibido.
4. `applyToBench` reaproveita `currentPlatformData.pose` e chama `/apply_pose`. Enquanto aguarda, o texto do botão muda para “Aplicando...”.
5. `initLocalTelemetryWS` estabelece o WebSocket, mantido ativo por heartbeat; mensagens `motion_tick.pose_cmd` atualizam apenas o preview, enquanto o restante passa por `normalizeTelemetry`/`applyLiveTelemetry` para alimentar o canvas live e `updateLiveMeasures`.
6. `updateMPUData` mostra/oculta o painel do sensor conforme a telemetria inclua campos `mpu` e `quaternions` válidos.

## Telemetria e Serial

- **Inicialização**: `checkExistingConnection` (GET `/serial/status`) sincroniza o estado da porta e dispara `initLocalTelemetryWS` se já houver conexão.
- **WebSocket**: utiliza `WS_URL` definido em `common.js`, registra heartbeat de 3 s e força reconexão quando fica mais de 5 s sem mensagens enquanto `serialConnected` é verdadeiro.
- **MPU/Recalibração**: o botão “Recalibrar” bloqueia interação durante o request `POST /serial/send` e usa `showToast`/`apply-error` para feedback.
- **Serial Manager**: funções comuns (`listar portas`, `conectar`, `desconectar`) vêm de `common.js`, reaproveitando os mesmos botões da página controller.

## Passo a Passo de Uso

1. **Iniciar backend**
   ```bash
   cd interface/backend
   python app.py
   ```
   Servidor disponível em `http://localhost:8001`.
2. **Abrir o frontend**: carregar `interface/frontend/kinematics.html` em um navegador (Chrome recomendado).
3. **Conectar ao ESP32**:
   - Clique em “Atualizar” para listar portas.
   - Escolha a porta correta e clique em “Conectar”.
   - O indicador muda para verde e mostra o nome da porta.
4. **Montar e validar a pose**:
   - Ajuste sliders ou digite valores.
   - Clique em “Calcular Posição” para obter comprimentos e preview 3D.
5. **Aplicar na bancada (opcional)**:
   - Confirme se todas as barras estão verdes (válidas) e se a pose faz sentido.
   - Clique em “Aplicar na Bancada”. A resposta mostra no toast/log.
6. **Acompanhar telemetria**:
   - Observe `canvas-live`, medidas reais e painel do MPU para validar o movimento físico.

## Configurações Avançadas

- **Limites dos sliders** (`interface/frontend/kinematics.html`): ajuste os atributos `min`/`max` dos inputs para refletir novos envelopes mecânicos.
- **Valores padrão** (`resetPosition` em `kinematics.js`): troque os valores atribuídos aos campos quando o usuário clica em “Resetar”.
- **Parâmetros de reconexão** (`kinematics.js`): modifique `heartbeatTimer`, `wsTimer` e `scheduleReconnect` para tornar o watchdog mais agressivo ou permissivo.
- **Formatação do MPU**: personalize o texto montado em `updateMPUData` caso queira suprimir o quaternion ou mudar o formato numérico.
- **Toasts/textos**: mensagens globais ficam concentradas em `showToast` e elementos `error-message`/`apply-error`, facilitando tradução ou ajustes de UX.

## Troubleshooting

- **"Pose inválida" ao calcular**: reduza ângulos/translações, verifique limites (curso 500–680 mm) e consulte logs do backend para entender o motivo do `valid=False`.
- **Botão “Aplicar” não aparece**: execute “Calcular Posição” novamente; o botão só fica visível quando `currentPlatformData` existe e `valid === true`.
- **Telemetria parada**: cheque se o backend está enviando mensagens em `/ws/telemetry`; observe o console do navegador para ver se o heartbeat está tentando reconectar.
- **Painel do MPU oculto**: somente é exibido quando `mpu.roll/pitch/yaw` chegam como números. Garanta que o firmware esteja publicando esses campos.
- **Recalibração falhou**: confirme a conexão serial e se o comando `recalibra` é reconhecido pelo firmware (veja o terminal do backend para erros).

## Autor

**Guilherme Miyata** - Instituto Federal de São Paulo (IFSP)
Trabalho de Conclusão de Curso - 2025

---

<a href='https://github.com/g-Miyata'>Github</a><br>
<a href='www.linkedin.com/in/g-miyata'>Linkedin</a><br>
<a href='https://www.g-miyata.com'>Portfólio</a>

**Última atualização:** Novembro 2025

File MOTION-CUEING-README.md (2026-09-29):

# Simulador de voo e Orientação do avião (FlightGear)

## Visão Geral

Duas telas usam o mesmo motor (`interface/backend/cueing.py`), cada uma com um perfil:

- **Simulador de voo** (`/simulador-voo`, perfil `washout`): motion cueing. A plataforma reproduz as **sensações** do voo, acelerações e rotações, e não a inclinação que se vê.
- **Orientação do avião** (`/orientacao-voo`, perfil `attitude`): a plataforma copia roll e pitch do avião, escalados e limitados a ±12°, em altura fixa.

Nas duas, o botão **Rodar no FlightGear** abre o FlightGear com o Embraer ERJ145 na pintura do IFSP. O avião voa o voo gravado **sincronizado com a plataforma** e a imagem aparece dentro da página. Instalação, uso e erros comuns estão em [FLIGHTGEAR-SETUP.md](FLIGHTGEAR-SETUP.md). A antiga ponte roll/pitch por Telnet (`fg-bridge.py` sem opções, rotas `/flight-simulation/*`) continua só para a interface `/antigo`.

O algoritmo é o **washout clássico** (Reid & Nahon), com um detalhe próprio desta bancada: os pistões são lentos (~10 a 16 mm/s, pelos parâmetros ajustados aos ensaios), então a pose final passa por um **limitador de velocidade das pernas**. A plataforma nunca recebe um comando mais rápido do que consegue seguir, e a tela mostra o que ela realmente entrega.

Dá para usar de dois jeitos:

- **Voos gravados:** clique em Play. O FlightGear é opcional (só para ver o avião). O repositório já traz uma rotina, `interface/simulation/flights/demo-erj145-sbgr-circuito.json` (5 min 58 s), gravada de dia na pista 27R de Guarulhos:
  - apresentação do ERJ145 do IFSP (~30 s), com a câmera girando em volta do avião parado e mostrando a pintura enquanto os motores dão partida;
  - decolagem e subida com recolhimento do trem;
  - circuito de tráfego pela esquerda, sobre a cidade, com puxada e picada, balanço de asas e curva em S na perna do vento;
  - base e final pela rampa de 3°;
  - arredondamento, pouso no eixo, frenagem e parada.
- **Ao vivo:** o FlightGear manda os dados por UDP e a plataforma segue o voo em tempo real. Também dá para gravar voos novos por aqui.

### O que esperar do movimento

O Simulador de voo é fiel às **sensações**: numa curva coordenada de 45°, o piloto não é empurrado para o lado (a inclinação compensa a força centrífuga), então a plataforma quase não inclina. Ela dá o início da rolagem e volta devagar ao centro, como os simuladores profissionais. O que mais aparece é a inclinação sustentada da decolagem e da subida. Na rotina do ERJ, com os parâmetros padrão, a plataforma chega a ~2° de roll e ~8° de pitch, e o comando traz até 23 mm de surge e 24 mm de heave. O pouso aparece como o toque (pico de ~2,8 g no piloto) e a frenagem (−5 m/s², a plataforma recua ~11 mm). Com pistões a ~9 mm/s, essas translações ficam abaixo do que o corpo percebe. Para uma apresentação em que o público compara com o avião na tela, a **Orientação do avião** é a que "bate com o que se vê" (até 12° de roll no mesmo voo).

## Arquitetura e Fluxo de Dados

```
FlightGear --UDP 60 Hz--> fg-bridge.py --cueing --WebSocket--> backend /cueing/ingest
 (protocolo genérico          (converte unidades,                 (washout + limites +
  stewart-cueing)              reconecta)                          serial a 60 Hz)
                                                                       |
                         /ws/telemetry (cueing_tick, 30 Hz)            |  replay de voo gravado v2:
                                        v                              v  UDP 60 Hz (stewart-visual)
                       telas Simulador de voo / Orientação       FlightGear sem física (ERJ145)
                                        ^                              |
                                        +------ /fg/stream (MJPEG) ----+
```

- **FlightGear como tela (`interface/backend/flightgear.py`):** `/fg/check` confere FlightGear, FGData, ERJ145, pintura, protocolos, portas e memória, e devolve a correção de cada item. `/fg/launch` instala a pintura e abre o `fgfs` com `--fdm=null`, a entrada `stewart-visual` e a Chase View. `/fg/status` acompanha a abertura e informa queda (com o log) ou travamento. `/fg/stream` repassa o MJPEG do servidor HTTP do FlightGear (`/screenshot?stream=y`). Durante o replay, o motor manda a posição, a atitude, o trem, os flaps e as superfícies interpolados a 60 Hz: o backend é o relógio, então pausa e velocidade valem para os dois.

- **FlightGear:** `interface/simulation/fgdata/Protocol/stewart-cueing.xml` define uma linha de texto por frame com força específica no piloto (`/accelerations/pilot/*`), velocidades angulares p, q, r, atitude, velocidade, altura e as flags de pausa/replay. A pasta entra no FlightGear pela opção `--data`, sem copiar nada para o FGData.
- **Ponte (`fg-bridge.py --cueing`, código em `cueing_bridge.py`):** recebe o UDP, converte ft/s² para m/s² e repassa cada frame ao backend por WebSocket. Se o backend atrasa, descarta os frames mais velhos.
- **Backend (`interface/backend/cueing.py`):** roda o washout, encolhe poses fora do curso, limita a velocidade das pernas e envia `spmm6x` a 60 Hz quando a plataforma está engatada. Publica `cueing_tick` no WebSocket de telemetria. O `app.py` só cria o motor, inclui as rotas e desliga o cueing na parada de emergência.

### Por que UDP e não Telnet

O Telnet é pergunta e resposta: cada propriedade custa uma ida e volta, e a ponte antiga lê só duas (roll e pitch) a ~30 Hz. O motion cueing precisa de ~15 valores coerentes do **mesmo frame**, com o menor atraso possível. A saída genérica UDP do FlightGear empurra tudo junto a cada frame (até 60 Hz), sem polling, e um pacote perdido simplesmente é substituído pelo próximo. O Telnet continua sendo usado pela ponte antiga.

## Voos gravados

`interface/simulation/flights/*.json`, formato `stewart-cueing-flight`:

- **v1:** colunas `t, fx, fy, fz, p, q, r, roll, pitch, heading, ias, agl, alt, wow`. Movem a plataforma.
- **v2:** as mesmas colunas mais `lat, lon, gear, flaps, elevator, aileron, rudder, speedbrake`. O FlightGear também consegue redesenhar o voo.
- **v3:** v2 mais a câmera (`cam_view, cam_hdg, cam_pitch, cam_fov, cam_dist`: vista, giro, inclinação, zoom e distância da Chase View). No replay, o FlightGear repete o mesmo enquadramento, inclusive a apresentação do avião; nos voos v1 e v2 a câmera fica livre. Toda gravação feita com o protocolo atual já sai em v3.

## Algoritmo

Entrada nos eixos do avião (x frente, y direita, z baixo). Saída na pose da plataforma (x frente, y esquerda, z cima; convenção ZYX de `StewartPlatform`, em que pitch positivo **abaixa** a frente). Por isso pitch e yaw trocam de sinal no mapeamento.

| Canal | Entrada | O que faz |
| --- | --- | --- |
| Inclinação (tilt) | Força específica x, y escalada (`f_scale`) | Passa-baixa e `asin(f/g)`: a gravidade empurra o ocupante como a aceleração sustentada faria. Taxa limitada (`tilt_rate_max`) para ficar abaixo do limiar do ouvido interno. Reproduz também a atitude sustentada (subida, descida). |
| Translação | Força específica em torno de 1 g, escalada (`trans_scale`) | Passa-alta de 3ª ordem até deslocamento: o solavanco aparece e o tampo volta ao centro sozinho. Usar a força específica, e não a aceleração cinemática, evita a pista lateral falsa das curvas coordenadas. |
| Rotação | p, q, r escalados (`rot_scale`, `yaw_scale`) | Passa-alta de 2ª ordem integrado: dá o início das rolagens e arfagens e depois volta ao zero. |

Depois do washout, a pose passa por três travas: limites por eixo (`x_max` … `yaw_max`), encolhimento na direção do neutro até caber no curso dos pistões e limite de velocidade das pernas (`leg_speed_max`). O mesmo limitador faz as transições de engatar (a partir da pose medida) e de soltar (até o neutro).

Os gráficos comparam o que o piloto sente no avião com o que o ocupante sente na plataforma (aceleração do tampo + gravidade pela inclinação), ao vivo e na análise de voos gravados.

### Limitação física

Com ~10 mm/s por perna, a plataforma inclina no máximo ~2°/s e não consegue dar o "tranco" do início de uma aceleração (onset). O que ela reproduz bem são as pistas lentas: aceleração sustentada na decolagem, subida e descida, e o início das rotações. Na rotina de demonstração, com os parâmetros padrão, o limitador de velocidade atua em ~28% do tempo e nenhuma pose precisa ser encolhida. Se os pistões reais forem mais rápidos do que o simulador indica, aumente `leg_speed_max`.

## Execução

### Voo gravado (sem FlightGear)

1. Suba o backend e abra a tela **Motion cueing**.
2. Conecte a bancada ou o simulador no topo e clique em **Engatar**.
3. Em **Voos gravados**, clique em **Play**. Velocidade de 0,5× a 2× e repetição ficam logo acima da lista.

Sem serial conectada, tudo roda e aparece no 3D, mas nada se move. O ícone de gráfico ao lado de cada voo abre a **análise**: o voo inteiro passado pelo washout com os parâmetros atuais, com picos por eixo e o quanto do tempo o limitador atuou.

### Ao vivo

```powershell
# 1. FlightGear com a saída UDP (e --httpd para o MCP do FlightGear)
powershell -File interface\simulation\start-flightgear-cueing.ps1 -Aircraft c172p -Airport SBGR

# 2. Ponte (backend já rodando)
cd interface\simulation
python fg-bridge.py --cueing
```

O launcher abre na **Chase View** (terceira pessoa, atrás do avião), para quem assiste ver a orientação do avião de fora da cabine; `-View 0` volta para a cabine e `-View 1` dá a câmera orbital. O piloto de demonstração também escolhe a Chase View ao decolar.

O launcher usa o ERJ145 do IFSP por padrão (`-Aircraft c172p` para o Cessna). Na aba **Ao vivo**, confira "Recebendo do FlightGear". **Gravar voo** guarda um arquivo novo em `interface/simulation/flights/`.

Para refazer a rotina de demonstração, `python fly-demo.py` (na mesma pasta) faz tudo sozinho com o ERJ145: a apresentação com a câmera enquanto os motores dão partida, a decolagem, o circuito com as manobras e o pouso (o C172P só decola e faz manobras). O piloto está em `demo-flight.nas` e vai pela API HTTP do FlightGear, porque o Nasal não lê arquivos fora das pastas do simulador.

### Variáveis de ambiente da ponte

- `STEWARD_API_BASE` (padrão `http://localhost:8001`): backend.
- `FG_CUEING_UDP_HOST` / `FG_CUEING_UDP_PORT` (padrão `127.0.0.1:5510`): onde ouvir o FlightGear.
- `FG_RECONNECT_DELAY` (padrão `2.0` s).

## API

| Rota | Descrição |
| --- | --- |
| `GET /cueing/status` | Fonte, modo (`off`, `engaging`, `on`, `releasing`), ponte, replay, gravação, eventos e parâmetros |
| `GET/POST /cueing/params` | Lê ou troca os parâmetros (valem na hora); `POST /cueing/params/save` grava em `cueing_params.json` |
| `POST /cueing/engage` / `release` | Engata com `{profile: "washout" \| "attitude"}` (transição suave a partir da pose medida) ou volta ao neutro |
| `POST /cueing/record/start` / `stop` / `discard` | Gravação de voos ao vivo |
| `GET /cueing/flights` | Voos gravados; `GET /cueing/flights/{id}/analysis` roda o washout no voo inteiro; `POST /cueing/flights/{id}/delete` apaga |
| `POST /cueing/replay/start` / `update` / `stop` | Toca um voo (perfil, velocidade, repetição, pausa, `visual` para o FlightGear) |
| `GET /fg/check`, `GET /fg/status`, `POST /fg/launch`, `POST /fg/stop`, `GET /fg/stream` | FlightGear como tela do voo gravado |
| `WS /cueing/ingest` | Entrada da ponte: uma amostra JSON por mensagem |

## Segurança Operacional

- **Parada de emergência** (botão PARAR ou Esc) desliga o cueing e o replay antes de congelar os atuadores. O envio serial acontece sob o mesmo lock, então nenhum comando do cueing sai depois que a parada começa.
- Não engata com uma rotina rodando nem com a simulação de voo antiga liberada, e desengata sozinho se uma delas começar ou se a serial cair.
- Sem dados do FlightGear por 0,5 s, volta ao neutro. Com o FlightGear pausado, segura a última pose.
- Fechar a aba solta a plataforma (`/cueing/release` via `sendBeacon`), se for a tela dona da plataforma.
- Só um perfil manda por vez: a outra tela avisa "engatada pela tela …" e não engata até a primeira soltar.
- Se o FlightGear cair no meio do voo, a plataforma continua tocando, e a tela mostra o motivo.
- **Inverter pitch** (nos parâmetros das duas telas) corrige o sentido se, na bancada, a frente física da cadeira for o lado −X.

## Testes

`interface/backend/tests/test_cueing.py` cobre os sinais de cada canal (aceleração → nariz para cima, curva coordenada sem pista lateral, rolagem à direita → roll positivo, guinada, heave), o washout de volta ao neutro, o limitador de velocidade e de curso, engatar/soltar, parada de emergência, conflito com rotinas, gravação, análise, replay e as rotas.

## 👤 Autor

**Guilherme Miyata** - Instituto Federal de São Paulo (IFSP)
Trabalho de Conclusão de Curso - 2025

---

<a href='https://github.com/g-Miyata'>Github</a><br>
<a href='www.linkedin.com/in/g-miyata'>Linkedin</a><br>
<a href='https://www.g-miyata.com'>Portfólio</a>

**Última atualização:** Setembro 2026

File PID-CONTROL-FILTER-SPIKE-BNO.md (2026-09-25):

# Firmware PID com Filtro Anti-Spike (ESP32-S3)

## Visão Geral

`esp32s3_codes/stewart-platform-control/pid-control-filter-spike-bno/pid-control-filter-spike-bno.ino` é o firmware responsável por fechar o loop dos seis atuadores lineares da plataforma de Stewart. Ele recebe a referência de posição via serial (em milímetros), lê o feedback analógico dos encoders lineares, aplica filtro anti-spike + mediana e gera comandos PWM com feedforward, anti-windup e compensações individuais. O mesmo firmware também escuta dados de orientação via ESP-NOW para exibir roll/pitch/yaw (MPU6050 ou BNO085) e usa esse canal para recalibração remota do sensor.

## Principais Recursos

- **Recepção ESP-NOW híbrida**: detecta automaticamente pacotes `OrientationData` (MPU6050 – roll/pitch/yaw) ou `TelemetryData` (BNO085 – inclui quaternions), mantendo os valores em variáveis voláteis.
- **Filtro anti-spike dinâmico** combinado com mediana-3 e média móvel (parametrizável) para suavizar os sinais de feedback.
- **PID por pistão** (`Kp/Ki/Kd` independentes) com feedforward assimétrico (`U0_adv/U0_ret`), offset de curso (mm) e deadband ajustável.
- **Controles manuais** via serial: seleção de pistão, avanço/recuo com PWM fixo (`A`/`R`) e retorno ao PID (`OK`).
- **Calibração eletrônica**: cada canal possui par `V0/V100` e flag `hasCal`, permitindo mapear tensão (0–3.3V) para mm.
- **Telemetria CSV** contínua (33 ms) incluindo setpoint, posições reais, PWM aplicado e orientação (com ou sem quaternions).
- **Proteções internas**: limitação de integrador, anti-windup com tracking (`Tt_tracking`), PWM mínimo configurável. Ainda **não há** watchdog de serial: se o PC parar de enviar, o último setpoint continua valendo.

## Arquitetura Geral

| Camada | Descrição |
| --- | --- |
| ESP-NOW RX (`setupEspNowReceiver`) | Configura o ESP32-S3 como STA, inicializa ESP-NOW e registra `onReceive`. Cada pacote recebido atualiza `oriRoll/Pitch/Yaw` e, no caso do BNO085, `oriQw/Qx/Qy/Qz`. |
| Aquisição analógica | `readFeedbackVoltages` realiza `analogRead` múltiplas vezes, salva no buffer para mediana e atualiza `fbV_raw`. |
| Filtragem | `filterFeedbackVoltage` aplica mediana-3, spike detection (rejeita valores que variam além de `SPIKE_THRESH` proporcional ao desvio) e média móvel (`MA_N`). Resultado em `fbV_filt`. |
| Conversão para mm | `voltsToMM` usa `V0/V100 + offset_mm` e saturação (`Lmm`) para obter `y_mm`. |
| Controle PID | Dentro da rotina principal (`loop`), para cada pistão calcula erro `e_mm`, derivada, integra com leak/anti-windup e gera PWM limitado. Feedforward assimétrico compensa zona morta. |
| Comandos manuais | Flags `manual_retract/manual_advance` permitem aplicar PWM fixo (`RETRACT_PWM/ADV_PWM`) apenas no pistão selecionado (`selIdx`). |
| Serial Parser | Aceita comandos textuais (`sel=`, `spmm=`, `spmm6x=`, `kpmm=`, etc.) separados por `\n`, atualizando o estado imediatamente. |
| Telemetria | A cada 33 ms imprime CSV com cabeçalho dinâmico (adiciona colunas de quaternions quando presentes). |

## Pinagem e PWM

- **Feedback analógico (`FB_PINS`)**: `{1, 2, 3, 4, 5, 6}` (use ADC1 para ruído menor).
- **PWM (`PWM_PINS`)**: `{8, 18, 9, 10, 11, 12}` usando LEDC (freq. 20 kHz, resolução 8 bits).
- **IN1/IN2 por pistão (`pistons[]`)**: `{{16, 17}, {13, 14}, {35, 36}, {21, 38}, {39, 37}, {41, 42}}` controla o sentido (avançar/recuar/free). Ex.: pistão 1 usa GPIO16/17.

## Principais Parametrizações

| Variável | Descrição |
| --- | --- |
| `Lmm[6]` | Curso útil de cada atuador (mm). |
| `SP_mm[6]` | Setpoint atual (mm). |
| `Kp_mm/Ki_mm/Kd_mm` | Ganhos PID individuais. |
| `U0_adv/U0_ret` | Feedforward para compensar zona morta em avanço/recuo. |
| `offset_mm` | Compensação fixa no feedback (ex.: +2 mm). |
| `deadband_mm` | Janela onde o PID desliga (mantém free e esvazia integrador). |
| `MIN_PWM` | PWM mínimo aplicado quando o controle exige movimento (evita ficar abaixo do atrito estático). |
| `T_leak`, `Tt_tracking`, `I_LIM` | Constantes de anti-windup e escoamento de integrador. |

## Comandos Serial

Todos os comandos são enviados via USB/Serial na forma `texto
` (115200 baud). Os comandos de ganho, curso, calibração, feedforward e offset valem para o **pistão selecionado** com `sel=N`, e não recebem índice. O backend envia `sel=N` e o comando dentro de um mesmo bloqueio, para duas requisições não se misturarem.

| Comando | Função |
| --- | --- |
| `sel=N` | Seleciona o pistão `1..6` (usado pelos comandos abaixo e pelo modo manual). |
| `spmm=VAL` | Setpoint (mm) igual para os seis pistões. |
| `spmm6x=v1,v2,v3,v4,v5,v6` | Seis setpoints de uma vez (usado pela cinemática, rotinas, joystick e IMU). |
| `spmmN=VAL` | Setpoint do pistão N (1-6). |
| `kpmm=VAL` / `kimm=VAL` / `kdmm=VAL` | Ganho P/I/D do pistão selecionado. |
| `kpall=VAL` / `kiall=VAL` / `kdall=VAL` | Mesmo ganho para todos. |
| `dbmm=VAL` | Zona morta do erro (mm): abaixo disso o PWM é zerado. |
| `minpwm=VAL` | PWM mínimo (0-255). |
| `lmm=VAL` | Curso útil do pistão selecionado (satura o setpoint). |
| `vmaxmmps=VAL` | Velocidade máxima plausível (mm/s) do filtro anti-spike. |
| `cal=V0,V100` | Calibração de tensão (0% e 100% do curso) do pistão selecionado. |
| `zero` / `mark100` | Usa a leitura atual como `V0` / `V100` do pistão selecionado. |
| `v?` | Mostra a tensão e a posição do pistão selecionado. |
| `u0a=VAL` / `u0r=VAL` | Feedforward de subida/descida (PWM) do pistão selecionado. |
| `u0aall=VAL` / `u0rall=VAL` | Feedforward para todos. |
| `offset=VAL` / `offsetall=VAL` | Offset da leitura (mm) do pistão selecionado / de todos. |
| `A` / `R` | Modo manual: avança/recua o pistão selecionado com PWM fixo (os outros ficam sem PWM). |
| `OK` | Sai do modo manual e volta ao PID (zera o integrador). Também é enviado pela parada de emergência. |
| `recalibra` | Pede ao transmissor ESP-NOW (BNO085/MPU6050) para refazer o zero da orientação. |
| `fc=...` | Obsoleto: ignorado (o filtro atual é mediana-3 + limitador de inclinação). |

> O dispositivo virtual do backend (`interface/backend/simulated_device.py`) interpreta esta mesma tabela. Se mudar o parser do firmware, atualize o simulador e os testes em `interface/backend/tests/`.

## Fluxo Operacional

1. **Boot**: configura serial, PWM, leitura analógica, filtros e ESP-NOW (`setupEspNowReceiver`).
2. **Loop principal**:
   - Lê a serial (parser no início de `loop()`), atualizando qualquer parâmetro.
   - Atualiza `dt` (baseado em `millis()`), lê tensões e filtra.
   - Calcula feedback em mm e aplica PID ou modo manual conforme flags.
   - Escreve PWM (`ledcWrite`) e define direção (`setDirAdvance/Return/Free`).
   - A cada 33 ms, imprime linha CSV com telemetria.
3. **ESP-NOW**: sempre que chega pacote, atualiza `oriRoll/Pitch/Yaw` (usados na telemetria) e guarda `lastSenderMac` para eventuais respostas.

## Exemplo de Telemetria (MPU6050)

```
ms;SP_mm;Y1;Y2;Y3;Y4;Y5;Y6;PWM1;PWM2;PWM3;PWM4;PWM5;PWM6;Roll;Pitch;Yaw
12345;10.000;9.85;10.12;9.97;9.90;9.88;10.01;80;75;78;82;79;81;1.24;-0.50;0.02
```

No caso do BNO085 o cabeçalho inclui `Qw,Qx,Qy,Qz` e a linha adiciona esses valores ao final.

## Dicas de Uso

1. **Calibração dos sensores lineares**: selecione o pistão (`sel=N`) e use `cal=V0,V100`, ou posicione no batente e use `zero` / `mark100`. O firmware já vem com `V0=0,25 V` e `V100=3,3 V` para todos.
2. **Tunagem PID**: ajuste `Kp/Ki/Kd` via comandos individuais ou globais. O feedforward (`u0a/u0r`) ajuda a reduzir o esforço do PID quando os atuadores entram no regime não linear.
3. **Anti-spike**: o filtro é mediana de 3 leituras + limitador de variação baseado em `vmax_mm_s`. Se o ambiente estiver ruidoso, reduza `vmaxmmps` via serial.
4. **Telemetria**: use `pio device monitor` ou qualquer terminal serial configurado em 115200 baud para registrar os dados CSV. Importando em um spreadsheet fica fácil comparar setpoint vs. real.
5. **Integração com o backend**: o FastAPI envia `spmm6x=` com os cursos calculados (mm); a ida para o home das rotinas usa `spmm1..6=`.
6. **Sem hardware**: conecte a porta `SIMULADOR` na interface. O dispositivo virtual responde aos mesmos comandos e reproduz a dinâmica medida dos atuadores.

## Estrutura do Projeto

```
esp32s3_codes/
├── stewart-platform-control/
│   ├── pid-control-filter-spike-bno/pid-control-filter-spike-bno.ino   ← firmware principal
│   ├── BNO085/BNO085.ino                                               ← transmissor ESP-NOW (BNO085)
│   └── mpu-6050/mpu-6050.ino                                           ← transmissor ESP-NOW (MPU-6050)
└── others/                                                              ← sketches de teste antigos
```

## 👤 Autor

**Guilherme Miyata** - Instituto Federal de São Paulo (IFSP)  
Trabalho de Conclusão de Curso - 2025

---

<a href='https://github.com/g-Miyata'>Github</a><br>
<a href='https://www.linkedin.com/in/g-miyata'>Linkedin</a><br>
<a href='https://www.g-miyata.com'>Portfólio</a>

**Última atualização:** Novembro 2025

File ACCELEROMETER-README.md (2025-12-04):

# Controle por Acelerômetro (MPU/BNO085) - Plataforma de Stewart

## Visão Geral

`accelerometer.html` + `accelerometer.js` fornecem uma interface leve para controlar roll/pitch/yaw da plataforma usando dados de um MPU-6050 ou BNO085. O frontend mostra o sensor em tempo real, calcula as medidas dos pistões sem renderização 3D e, quando autorizado, envia comandos diretos ao backend FastAPI (`/mpu/control`) para aplicar o movimento no hardware.

## Características

- Indicadores de conexão serial, porta ativa e botão de recalibração (`recalibra`) para alinhar o sensor.
- Painel “Controle Ativo” com toggle principal e slider de sensibilidade (0–100% → escala 0.0–1.0 usado nos ângulos).
- Exibição contínua de Roll/Pitch/Yaw com barras percentuais (clamp ±5°) e, quando presente, quaternion completo do BNO085.
- Pré-visualização das medidas dos seis pistões (cores verde/vermelho conforme validade), calculada via `/calculate`.
- WebSocket dedicado (`WS_URL`) com heartbeat, reconexão automática e filtro para mensagens `telemetry_mpu` ou `telemetry_bno085`.
- Aplicação opcional da pose no hardware: os comandos só são enviados ao ESP32 se `controlEnabled` estiver marcado e a serial conectada.

## Arquitetura

### Backend (`interface/backend/app.py`)

- `POST /serial/ports`, `/serial/open`, `/serial/close`, `/serial/status`: gerenciamento da porta USB (reutilizado de `common.js`).
- `POST /serial/send`: recebe `{ "command": "recalibra" }` para disparar a rotina de calibração no ESP32.
- `POST /calculate`: calcula os comprimentos absolutos e percentuais dos atuadores para a pose estimada (visualização no painel de pistões).
- `POST /mpu/control`: aplica a pose no hardware (roll/pitch/yaw limitados, x/y fixos, z = 530 mm por padrão, além do parâmetro `scale`).
- WebSocket `/ws/telemetry`: envia mensagens com `type=telemetry_mpu` ou `telemetry_bno085`, contendo `mpu` (roll/pitch/yaw) e, quando disponível, `quaternions`.

### Frontend (`interface/frontend/scripts/accelerometer.js`)

- Constantes importantes:
  - `DEFAULT_Z_HEIGHT = 530` mm (pose neutra).
  - `WS_UPDATE_INTERVAL` (~30 FPS) e `CONTROL_UPDATE_INTERVAL` (~10 Hz) para limitar chamadas.
  - `limitAngles()` restringe os ângulos entre –5° e +5°.
- `updateMPUDisplay` e `updateQuaternionDisplay` mantêm o painel numérico/barras sincronizado.
- `calculateKinematicsFromMPU(mpu)`:
  1. Limita ângulos recebidos.
  2. Aplica a escala definida pelo slider.
  3. Limita novamente.
  4. Monta a pose (X/Y=0, Z=DEFAULT_Z_HEIGHT).
  5. Chama `/calculate` e atualiza `currentPlatformData` + `updatePistonMeasures`.
- `sendMPUControl(mpu)`:
  - Respeita `controlEnabled`, `serialConnected` e `CONTROL_UPDATE_INTERVAL`.
  - Limita/escala ângulos e envia `POST /mpu/control` (JSON com pose + scale).
- `initTelemetryWS()`:
  - Garante que apenas um socket exista, limpa timers e abre `WS_URL`.
  - Implementa heartbeat (3 s) e reconexão se ficar >5 s sem mensagens.
  - Processa somente `telemetry_mpu`/`telemetry_bno085`, acionando `updateMPUDisplay`, `updateQuaternionDisplay`, `calculateKinematicsFromMPU` e `sendMPUControl` (quando ativo).
- `checkExistingConnection()`:
  - Consulta `/serial/status`, atualiza LED, botões e select.
  - Reabre o WebSocket, mostra toast e aplica a pose neutra (530 mm) via `/mpu/control`.
- `DOMContentLoaded` flow:
  1. Faz ping em `/serial/ports` para verificar backend.
  2. Executa `loadSerialPorts()` e `checkExistingConnection()`.
  3. Chama `calculateKinematicsFromMPU` com ângulos zero (preview inicial).
  4. Inicia `initCommonSerialControls()`, listeners de recalibração, toggle e slider.
  5. Sobrescreve `window.initTelemetryWS` para usar a versão local.

## Painéis da Página

1. **Status da Conexão** – LED com animação “pulse”, texto e porta atualizados em tempo real.
2. **Conexão Serial** – select de portas, botões Atualizar/Conectar/Desconectar (reutiliza estilos e lógica de `common.js`).
3. **Controle Ativo & Sensibilidade** – toggle “Controle Ativo”, slider `scale`, display percentual e botão “Recalibrar Referência”.
4. **Dados do Sensor** – valores numéricos de roll/pitch/yaw (+ barras progressivas) e, se disponível, card com quaternion `w/x/y/z`.
5. **Medidas dos Pistões** – grade com `preview-piston-1..6`, cores variando conforme `valid`.
6. **Checklist / Mensagens** – toasts informam backend offline, tentativa de controle sem serial, etc.

## Fluxo de Funcionamento

1. Usuário abre `accelerometer.html`.
2. Scripts carregam portas, verificam conexão existente e calculam uma pose inicial (sem movimentar a plataforma).
3. WebSocket passa a receber telemetria do MPU:
   - Roll/Pitch/Yaw aparecem no painel.
   - Os valores são limitados, escalados e usados para calcular os comprimentos dos pistões (preview).
4. Ao marcar “Controle Ativo”:
   - Cada atualização válida do sensor passa por `sendMPUControl`.
   - A função respeita o `CONTROL_UPDATE_INTERVAL` (~10 Hz) antes de chamar `/mpu/control`.
5. Botão “Recalibrar Referência” dispara `/serial/send` com `recalibra`, exibindo feedback via `showToast`.
6. Ao desconectar a serial ou sair da página, o toggle é desativado automaticamente (listener `beforeunload`).

## Passo a Passo de Uso

1. Rodar o backend (`python app.py`) e abrir `interface/frontend/accelerometer.html`.
2. Conectar o ESP32:
   - Clique em “Atualizar”, escolha a porta e pressione “Conectar”.
   - Confirme que o LED ficou verde (`Conectado` + porta exibida).
3. Ativar o sensor:
   - Verifique se Roll/Pitch/Yaw estão sendo recebidos (valores diferentes de `--`).
   - Se necessário, pressione “Recalibrar Referência” para zerar offsets.
4. Ajustar a sensibilidade pelo slider (100% = escala 1.0).
5. Marcar “Controle Ativo”.
   - Se aparecer aviso de serial desconectada, reconecte antes de prosseguir.
6. Monitorar o painel de pistões e, se algum ficar vermelho, reduza os ângulos ou diminua a escala.
7. Desmarcar o toggle antes de desconectar ou encerrar o backend.

## Configurações Avançadas

- **Limites de ângulos**: edite `limitAngles()` para ampliar ou reduzir o envelope (ex.: ±8° para roll/pitch).
- **Sensibilidade**: mude o cálculo do slider (`scale = value / 100`) para suportar até 200% (basta alterar `max="200"` e o divisor).
- **Altura neutra**: ajuste `DEFAULT_Z_HEIGHT` caso a plataforma tenha h0 diferente de 530 mm.
- **Taxas de atualização**: personalize `WS_UPDATE_INTERVAL` e `CONTROL_UPDATE_INTERVAL` para balancear responsividade x tráfego serial.
- **Feedback numérico**: `updateCount` e `lastRateCheck` podem ser reutilizados para mostrar Hz efetivos (trecho comentado no HTML).
- **Isolamento das mensagens WebSocket**: a função `initTelemetryWS` pode ser adaptada para conviver com outros handlers usando um dispatcher central (ex.: em `ws-utils.js`).

## Troubleshooting

- **Painel mostra “Backend offline”**:
  - Confira o terminal do FastAPI; a página testa `/serial/ports` logo ao carregar e mostra toast de aviso se falhar.
  - Verifique se a porta TCP 8001 está disponível ou ajuste `API_BASE`.
- **Controle não aplica no hardware**:
  - Certifique-se de que `controlEnabled` está marcado e que `serialConnected` é `true`.
  - Observe o console: `sendMPUControl` registra mensagens quando sai cedo por throttle ou falta de serial.
- **Valores de roll/pitch travados**:
  - O WebSocket pode ter desconectado — veja se o log exibe “WebSocket sem mensagens há X s - reconectando”.
  - Clique em “Atualizar” e reconecte a porta para reabrir a telemetria.
- **Pistões sempre vermelhos**:
  - Os ângulos podem estar extrapolando o limite mesmo após o clamp — reduza a escala ou revise `DEFAULT_Z_HEIGHT`.
  - Confira se `/calculate` está retornando `valid=false` (mensagens aparecem no console).
- **Botão “Recalibrar” não faz nada**:
  - A serial precisa estar conectada; o código mostra toast “Conecte-se primeiro…” caso contrário.
  - Veja logs do backend para garantir que o firmware reconhece o comando `recalibra`.

## Autor

**Guilherme Miyata** - Instituto Federal de São Paulo (IFSP)  
Trabalho de Conclusão de Curso - 2025

---

<a href='https://github.com/g-Miyata'>Github</a><br>
<a href='www.linkedin.com/in/g-miyata'>Linkedin</a><br>
<a href='https://www.g-miyata.com'>Portfólio</a>

**Última atualização:** Novembro 2025

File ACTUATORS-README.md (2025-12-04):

# Painel PID & Atuadores - Plataforma de Stewart

## Visão Geral

`actuators.html` reúne tudo o que é necessário para operar e depurar o controle PID de cada pistão: conexão serial, ajustes de setpoint (global e individual), monitoramento em tempo real, sintonização de ganhos/offsets/feedforward e comandos manuais direto para o ESP32. Os scripts `actuators.js` e `chart-utils.js` trabalham juntos para exibir telemetria via WebSocket (`/ws/telemetry`) e registrar dados em IndexedDB.

## Características

- Cartões de status e conexão serial padronizados (lista automática de portas, botões Conectar/Desconectar).
- Gráfico interativo (Chart.js) com até 6 pares “posição atual x setpoint” + gravação em IndexedDB e exportação CSV.
- Controles de setpoint global (todos os pistões) e individual, com histórico no console lateral.
- Envio de parâmetros PID: ganhos individuais, ganhos globais, feedforward (avanço/recuo) e offsets de curso.
- Comandos manuais rápidos (`/pid/manual/A|R|ok`) para testes ponto a ponto.
- Console integrado mostrando TX/RX e alertas, além de painel com últimos valores de telemetria.
- Reconexão automática do WebSocket enquanto `serialConnected` permanecer verdadeiro.

## Arquitetura

### Backend (`interface/backend/app.py`)

- Endpoints seriais: `GET /serial/ports`, `POST /serial/open`, `POST /serial/close`, `GET /serial/status`.
- Telemetria: WebSocket `/ws/telemetry` envia `Y` (posições), `sp_mm`, `mpu`, mensagens `raw`.
- PID:
  - `POST /pid/setpoint` – recebe `PIDSetpoint` (global e individual).
  - `POST /pid/gains`, `GET /pid/gains`, `GET /pid/gains/{piston}` – leitura/ajuste por pistão.
  - `POST /pid/gains/all` – aplica mesmos ganhos em todos os pistões.
  - `POST /pid/feedforward` e `/pid/feedforward/all` – U0 de avanço/recuo.
  - `POST /pid/settings` / `GET /pid/settings` – `dbmm` e `minpwm`.
  - `POST /pid/offset` e `/pid/offset/all` – correções de referência.
  - `POST /pid/manual/{action}` – ações discretas (A=avanço, R=recuo, ok=parar).
  - `POST /pid/select/{piston}` – seleciona pistão ativo para comandos manuais/offsets.

### Frontend (`actuators.html` + `actuators.js` + `chart-utils.js`)

- `chart-utils.js`:
  - `initDB()` cria `TelemetryDB.telemetry`.
  4 functions manage Chart data, recording, toggles, export.
- `actuators.js`:
  - `initLocalTelemetryWS()` abre WebSocket, monitora heartbeat (5 s) e chama `handleTelemetry`.
  - `handleTelemetry(data)` atualiza UI textual (`telem-sp`, `telem-yX`), injeta os dados no gráfico (via `updateChart`), registra log RX e calcula toasts.
  - `sendCommand`/`sendFreeCommand` auxiliam o terminal manual (enviando strings para `/serial/send`).
  - `sendSetpointGlobal`, `sendSetpointIndividual` chamam `/pid/setpoint` e atualizam `currentSetpoints`.
  - `sendPIDParams`, `sendFeedforward`, `sendOffsets` disparam para os endpoints correspondentes usando valores da UI.
  - `manualAdvance/Retact/Stop` usam `/pid/manual/A|R|ok`.
  - `checkExistingConnection()` retoma sessão aberta, atualiza select, guarda porta em `localStorage` e chama `initLocalTelemetryWS`.
  - `updateConnectionStatus()` roda periodicamente para manter LED e texto atualizados.
  - Ao carregar a página: inicializa IndexedDB + gráfico, aplica `initCommonSerialControls()`, inicia WebSocket e verifica serial.

## Seções da Página

1. **Status + Conexão Serial** – mesmo layout usado nas demais telas (select, atualizar, conectar, desconectar).
2. **Gráfico de Telemetria** – canvas principal com botões:
   - Iniciar/Pausar gravação.
   - Limpar dados.
   - Resetar zoom.
   - Exportar CSV.
   - Checkboxes por pistão para mostrar/ocultar curvas de posição e setpoint.
3. **Setpoints**:
   - Controle global: define `sp_mm` para todos de uma vez (slider + input).
   - Controle individual: inputs e botões por pistão.
4. **PID**:
   - Campos de Kp/Ki/Kd + feedforward (u0 avanço/recuo) por pistão.
   - Botões para aplicar nos seis simultaneamente.
5. **Offsets e Seleção de Pistão** – define offsets em mm e seleciona qual eixo está “armado” para comandos manuais.
6. **Controles Manuais** – botões Avançar / Recuar / Parar e campo para enviar comandos livres supervisionados.
7. **Console & Telemetria Instantânea** – área tipo terminal que lista TX/RX/time e pequenos cards com os últimos valores Y1…Y6, SP global e status da gravação.

## Fluxo de Funcionamento

1. Usuário conecta a porta → `initLocalTelemetryWS()` abre o WebSocket e começa a receber `telemetry`.
2. Cada mensagem:
   - Preenche `telem-yX` e `telem-sp`.
   - `updateChart()` adiciona um ponto (posições reais + setpoints guardados).
   - Se gravação estiver ativa (`chartRecording=true`), os pontos também vão para o IndexedDB.
3. Operações do painel enviam requisições REST:
   - Setpoints e ganhos usam JSON (`fetch` com body).
   - Feedforward “All” e setpoint global aproveitam query strings simples.
   - Comandos manuais/offsets logam no console com tag `[TX]` ou `[INFO]`.
4. “Exportar CSV” consulta IndexedDB completo e baixa o arquivo `telemetria_<timestamp>.csv`.
5. Ao sair ou trocar de página, `beforeunload` para e limpa o gráfico para evitar consumo de memória.

## Passo a Passo de Uso

1. Rodar o backend (`python app.py`) e abrir `actuators.html`.
2. Conectar a porta serial via seção “Conexão Serial”.
3. Iniciar o gráfico (botão “Iniciar Gravação”) se quiser histórico.
4. Ajustar setpoint global ou individual conforme o teste desejado.
5. Refinar PID:
   - Edite Kp/Ki/Kd dos pistões e clique em “Aplicar”.
   - Caso queira usar o mesmo valor em todos, utilize o bloco “Aplicar em Todos”.
6. Enviar offsets/feedforward caso detecte desvios.
7. Acionar “Avançar/Recuar/Parar” para testar movimentos discretos.
8. Exportar CSV para análise offline quando terminar.

## Configurações Avançadas

- **Janela do gráfico**: altere `maxDataPoints` (em `chart-utils.js`) para mais/menos pontos visíveis. Lembre-se que valores altos consomem mais CPU.
- **Persistência**: `TelemetryDB` fica no navegador. Limpe manualmente caso queira zerar sem usar “Limpar”.
- **Limiares de reconexão**: `heartbeatTimer` em `actuators.js` dispara reconexão após 5 s sem mensagens; ajuste se o backend tiver intervalos maiores.
- **Cores e layout**: `PISTON_COLORS` define RGBA para cada eixo – útil para refletir padrões usados em outras documentações.
- **Automação**: as funções globais (ex.: `window.sendSetpointGlobal`) permitem chamar comandos direto pelo console do navegador para scripts de teste.

## Troubleshooting

- **Gráfico não aparece**:
  - Confirme que Chart.js foi carregado antes de `chart-utils.js`.
  - Cheque a aba Console para erros de canvas inexistente (`id="telemetry-chart"`).
- **Sem dados no gráfico mesmo conectado**:
  - Veja se o backend realmente está transmitindo telemetria (procure logs `TX`/`RX` no console do backend).
  - Verifique se `window.serialConnected` está `true`. Caso contrário, o WebSocket não tenta reconectar.
- **`fetch /pid/...` retorna erro 422**:
  - Campos vazios ou inválidos (ex.: `NaN`). Insira números com ponto e em mm/graus coerentes.
- **Exportação CSV baixa arquivo vazio**:
  - Grave alguns segundos antes. Sem dados no IndexedDB o arquivo virá somente com cabeçalho.
- **Console mostra “WebSocket sem mensagens”**:
  - Pode ser apenas ausência temporária de telemetria; porém, se persistir, clique em “Desconectar”/“Conectar” para reabrir o socket e verifique cabos.

## Autor

**Guilherme Miyata** - Instituto Federal de São Paulo (IFSP)  
Trabalho de Conclusão de Curso - 2025

---

<a href='https://github.com/g-Miyata'>Github</a><br>
<a href='www.linkedin.com/in/g-miyata'>Linkedin</a><br>
<a href='https://www.g-miyata.com'>Portfólio</a>

**Última atualização:** Novembro 2025

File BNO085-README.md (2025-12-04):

# Firmware BNO085 – Transmissor ESP-NOW

## Visão Geral

`esp32s3_codes/BNO085/BNO085.ino` roda em um ESP32 (ou ESP32-S3) dedicado à leitura do IMU **SparkFun BNO08x**. Ele obtém quaternions + ângulos de Euler diretamente do sensor, aplica offsets de zero (recalibração por software) e envia os dados para o ESP32-S3 principal (controle PID) por ESP-NOW. A telemetria inclui roll/pitch/yaw compensados e o quaternion completo, permitindo que o backend escolha qual representação usar.

## Fluxo

1. **Inicialização**
   - Configura I2C (`Wire.begin(21, 22)`, 400 kHz).
   - Inicializa `BNO08x` no endereço padrão `0x4B` e habilita o *Rotation Vector* a cada 50 ms (~20 Hz).
   - Configura ESP-NOW em modo `WIFI_STA`, adiciona o peer do receptor (`receiverMac[]`) e registra o callback `onDataRecv`.
2. **Loop**
   - Aguarda eventos do BNO08x com `imu.getSensorEvent()`.
   - Lê os quaternions (`quatI/J/K/Real`) e converte para Euler com `quaternionToEuler`.
   - Aplica offsets (`offsetRoll/Pitch/Yaw`). Offsets são atualizados quando:
     - É a primeira leitura (`temOffset == false`).
     - Chega um comando `recalibra` via ESP-NOW (flag `pedidoRecalibra`).
   - Preenche o struct `TelemetryData` com Euler + quaternions e envia a cada `sendIntervalMs` (50 ms) utilizando `esp_now_send`.

## Estruturas ESP-NOW

```cpp
typedef struct {
  float roll, pitch, yaw;
  bool  recalibra;   // comando vindo do S3
} CommandData;

typedef struct {
  float roll, pitch, yaw;   // já compensados
  float qw, qx, qy, qz;     // quaternion bruto
  bool  recalibra;          // sempre false (mantido por compatibilidade)
} TelemetryData;
```

- **Recepção**: `onDataRecv` copia o `CommandData`. Se `recalibra == true`, levanta a flag `pedidoRecalibra`, tratada no `loop`.
- **Envio**: `ori` (TelemetryData) é atualizado com os ângulos compensados antes de chamar `esp_now_send`.

## Recalibração

- Quando o controlador marca “Recalibrar” (página `accelerometer.html`), o backend envia `recalibra` para o firmware PID, que repassa o comando via ESP-NOW ao transmissor BNO.
- Este firmware apenas “zera” os offsets atuais (armazenados em `offsetRoll/Pitch/Yaw`), sem precisar recalibrar o sensor fisicamente, garantindo resposta rápida.

## Configurações Importantes

| Constante | Descrição |
| --- | --- |
| `receiverMac[]` | MAC do ESP32-S3 principal (ajuste conforme o hardware). |
| `sendIntervalMs` | Intervalo de envio (50 ms ≈ 20 Hz). |
| `BNO08x_DEFAULT_ADDRESS` | Troque para `0x4A` se o breakout estiver configurado nesse endereço. |
| Pinos I2C | `Wire.begin(21, 22)` – altere conforme seu hardware. |

## Integração com o Backend

- O backend (`accelerometer.js` ou `kinematics.js`) consome os dados convertidos via `/ws/telemetry`. Quando o firmare PID encaminha uma request `recalibra`, ela chega até este transmissor, reiniciando a referência.
- A disponibilidade do quaternion permite que o frontend exiba tanto a forma “roll/pitch/yaw” quanto `q = w + xi + yj + zk`.

## Testes Rápidos

1. Compile/flash `BNO085.ino` com a biblioteca `SparkFun_BNO08x_Arduino_Library` (v1.0.6).
2. Abra o Serial Monitor (115200) e verifique:
   - MAC do transmissor.
   - Mensagem “BNO08x configurado!”.
   - Log “ESP-NOW pronto…”.
3. Mova o sensor – o Serial exibirá os ângulos enviados, e o firmware PID deverá começar a receber quaternions (observe a telemetria em `actuators.html` ou `accelerometer.html`).

## Arquivos Relacionados

- [PID-CONTROL-FILTER-SPIKE-BNO.md](PID-CONTROL-FILTER-SPIKE-BNO.md) – descreve como o receptores utiliza esta telemetria.
- [ACCELEROMETER-README.md](ACCELEROMETER-README.md) – mostra a interface que consome os dados do BNO085.

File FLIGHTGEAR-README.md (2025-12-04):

# FlightGear Simulation Bridge

## Visão Geral

Este guia descreve a ponte de simulação entre o FlightGear e a Plataforma de Stewart. O componente `interface/simulation/fg-bridge.py` lê roll/pitch do simulador via Telnet, limita amplitudes para manter a geometria segura e repassa poses ao backend FastAPI. O backend, por sua vez, calcula a cinemática inversa e envia os setpoints aos atuadores da plataforma real.

## Arquitetura e Fluxo de Dados

- **FlightGear (Telnet 5050)**: expõe propriedades `/orientation/roll-deg` e `/orientation/pitch-deg`.
- **fg-bridge (Python + httpx + flightgear_python)**:
  - Conecta ao Telnet do FlightGear (`FG_TELNET_HOST`, `FG_TELNET_PORT`).
  - Lê roll/pitch, aplica `clamp_angle` com limite configurável (`FG_ANGLE_LIMIT`, padrão 15°).
  - Monta pose segura com `z` e `yaw` fixos (`SAFE_Z`, `SAFE_YAW`).
  - Chama `POST /calculate` para validar workspace e obter pré-visualização.
  - Publica a pré-visualização em `POST /flight-simulation/preview` para que o frontend possa renderizar mesmo sem telemetria física.
  - Verifica a flag `GET /flight-simulation/status` (`enabled`) para saber se deve ou não controlar a plataforma.
  - Envia a pose final para `POST /apply_pose`, que encaminha os comprimentos aos atuadores via serial.
- **Backend (FastAPI)**: recebe poses, calcula cinemática inversa e repassa comandos ao ESP32-S3. Também alimenta o WebSocket `/ws/telemetry` usado pelo frontend para exibir a pré-visualização e o estado da simulação.

## Configuração

Variáveis de ambiente consumidas por `fg-bridge.py`:

- `STEWARD_API_BASE` (padrão `http://localhost:8001`) – base da API FastAPI.
- `STEWARD_APPLY_PATH` (padrão `/apply_pose`) – rota de aplicação de pose.
- `FG_TELNET_HOST` / `FG_TELNET_PORT` (padrão `localhost:5050`) – endereço do FlightGear.
- `FG_POLL_INTERVAL` (padrão `0.1` s) – período de leitura.
- `FG_RECONNECT_DELAY` (padrão `2.0` s) – tempo para tentar reconectar ao Telnet.
- `FG_ANGLE_LIMIT` (padrão `15.0` graus) – saturação de roll/pitch.
- `SAFE_Z` (padrão `540.0`) e `SAFE_YAW` (padrão `0.0`) – componentes fixos da pose enviada.

## Execução

1. No FlightGear, habilite o servidor Telnet: `--telnet=socket,in,30,localhost,5050,udp`.
2. Suba o backend (`uvicorn app:app --host 0.0.0.0 --port 8001`) e habilite a flag de simulação via endpoint ou UI.
3. Ajuste variáveis de ambiente se necessário e execute:
   ```bash
   cd interface/simulation
   python fg-bridge.py
   ```
4. Acompanhe os logs: conexões Telnet, ângulos lidos, preview aceito ou rejeitado, e aplicação da pose.

## Segurança Operacional

- A ponte só envia poses se `enabled` em `/flight-simulation/status` estiver ativo.
- Roll/pitch são saturados em `FG_ANGLE_LIMIT`; poses fora do workspace são descartadas ao cair na validação de `/calculate`.
- Reconexões ao Telnet são automáticas, minimizando perda de dados se o FlightGear reiniciar.

## Troubleshooting

- **Conexão recusada**: confirme porta `5050` e parâmetro `--telnet` no FlightGear.
- **Preview inválido**: reduza `FG_ANGLE_LIMIT` ou ajuste `SAFE_Z` para manter a plataforma dentro do curso mecânico.
- **Sem movimento na plataforma**: verifique se `/flight-simulation/status` retorna `{"enabled": true}` e se o backend está com a serial aberta.

## 👤 Autor

**Guilherme Miyata** - Instituto Federal de São Paulo (IFSP)  
Trabalho de Conclusão de Curso - 2025

---

<a href='https://github.com/g-Miyata'>Github</a><br>
<a href='www.linkedin.com/in/g-miyata'>Linkedin</a><br>
<a href='https://www.g-miyata.com'>Portfólio</a>

**Última atualização:** Novembro 2025

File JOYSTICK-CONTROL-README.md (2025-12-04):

# Sistema de Controle por Joystick - Plataforma de Stewart

## 📋 Visão Geral

Sistema completo de controle em tempo real da Plataforma de Stewart usando gamepad/joystick, integrado ao backend FastAPI e frontend Three.js.

## 🎮 Características

- **Controle em Tempo Real**: Mapeamento direto dos eixos do joystick para translação/rotação da plataforma
- **Limites de Segurança**: ±30mm de translação e ±8° de rotação (configuráveis)
- **Preview 3D em Tempo Real**: Visualização instantânea da pose calculada
- **Modo Dual**: Preview-only ou aplicação no hardware
- **Validação Automática**: Verifica limites dos atuadores antes de aplicar

## 🕹️ Mapeamento do Controle

### Stick Esquerdo

- **Horizontal (LX)**: Translação em X (±30mm)
- **Vertical (LY)**: Translação em Y (±30mm)

### Stick Direito

- **Horizontal (RX)**: Rotação Pitch (±8°)
- **Vertical (RY)**: Rotação Roll (±8°)

### Triggers (Futuro)

- **LT/RT**: não implementado ainda

### Zona Morta

- Valores menores que 0.1 (10%) são ignorados para evitar drift

## 🏗️ Arquitetura

### Backend (`app.py`)

#### Novo Modelo Pydantic

```python
class JoystickPoseRequest(BaseModel):
    lx: float = Field(0.0, ge=-1.0, le=1.0)  # Stick esquerdo X
    ly: float = Field(0.0, ge=-1.0, le=1.0)  # Stick esquerdo Y
    rx: float = Field(0.0, ge=-1.0, le=1.0)  # Stick direito X
    ry: float = Field(0.0, ge=-1.0, le=1.0)  # Stick direito Y
    lt: Optional[float] = None  # Trigger esquerdo
    rt: Optional[float] = None  # Trigger direito
    apply: bool = False  # Se True, aplica no hardware
    z_base: Optional[float] = None  # Z base (default = h0)
```

#### Endpoint: `POST /joystick/pose`

**Funcionalidades:**

1. Recebe eixos normalizados do joystick (-1..1)
2. Mapeia para valores físicos (mm e graus)
3. Calcula cinemática inversa
4. Valida limites dos atuadores
5. Se `apply=True` e válido, envia comando serial `spmm6x=...`
6. Retorna resposta completa com pose, comprimentos, pontos 3D

**Limites Físicos:**

```python
MAX_TRANS_MM = 30.0   # ±30mm
MAX_ANGLE_DEG = 30.0  # ±30°
```

**Exemplo de Request:**

```json
{
  "lx": 0.5,
  "ly": -0.3,
  "rx": 0.2,
  "ry": -0.1,
  "apply": true,
  "z_base": 432
}
```

**Exemplo de Response (válida):**

```json
{
  "valid": true,
  "applied": true,
  "pose": {
    "x": 5.0,
    "y": 3.0,
    "z": 432,
    "roll": 1.0,
    "pitch": 2.0,
    "yaw": 0.0
  },
  "lengths_abs": [590.2, 588.5, ...],
  "course_mm": [90.2, 88.5, ...],
  "base_points": [[305.5, -17, 0], ...],
  "platform_points": [[196.1, -238.5, 432], ...]
}
```

### Frontend

#### `joystick-control.js`

**Classe Principal: `JoystickController`**

```javascript
class JoystickController {
  constructor(config)
  setEnabled(enabled)          // Ativa/desativa controle
  setApplyToHardware(apply)    // Define se aplica no hardware
  getState()                   // Retorna estado atual
  destroy()                    // Limpa recursos
}
```

**Configuração:**

```javascript
const JOYSTICK_CONFIG = {
  DEADZONE: 0.1, // Zona morta (10%)
  UPDATE_RATE_MS: 50, // Taxa de envio ao backend (20Hz)
  PREVIEW_RATE_MS: 16, // Taxa de atualização 3D (≈60fps)
  MAX_TRANS_MM: 10.0,
  MAX_ANGLE_DEG: 10.0,
  Z_BASE: null, // null = usar h0 do backend
};
```

**Loops Independentes:**

1. **Loop de Preview** (`requestAnimationFrame`): Lê gamepad e atualiza UI/3D a ~60fps
2. **Loop de Backend** (`setInterval`): Envia comandos ao servidor a cada 50ms

#### `controller.js`

Script principal da página que:

- Inicializa preview 3D (Three.js)
- Cria instância do `JoystickController`
- Gerencia UI (checkboxes, valores, sliders)
- Conecta callbacks (onPoseChange, onError)
- Gerencia eventos de gamepad (conectar/desconectar)

#### `controller.html`

Página completa com:

- Header institucional (IFSP)
- Navegação entre páginas
- Status de conexão serial
- Painel de controle do joystick
- Instruções de uso
- Display de valores atuais (X, Y, Z, Roll, Pitch, Yaw)
- Preview 3D em tempo real

## 🚀 Como Usar

### 1. Iniciar Backend

```bash
cd interface/backend
python app.py
```

Backend rodará em `http://localhost:8001`

### 2. Abrir Frontend

Abra `interface/frontend/controller.html` no navegador

### 3. Conectar Porta Serial

1. Clique em "Atualizar" para listar portas
2. Selecione a porta do ESP32
3. Clique em "Conectar"

### 4. Conectar Gamepad

1. Conecte um gamepad USB ou Bluetooth
2. O sistema detectará automaticamente
3. Status mudará para "Conectado: [nome do gamepad]"

### 5. Ativar Controle

1. ✅ Marque "Ativar Controle por Joystick"
2. Mova os sticks - o preview 3D atualizará em tempo real
3. Valores de X, Y, Z, Roll, Pitch, Yaw serão exibidos

### 6. Aplicar no Hardware (Opcional)

⚠️ **ATENÇÃO: Só faça isso se a plataforma estiver segura!**

1. ✅ Marque "Aplicar no Hardware"
2. Movimentos do joystick agora controlam a plataforma real
3. Comandos `spmm6x=...` serão enviados via serial

## 🛡️ Segurança

### Limites Físicos Implementados

- **Translação X, Y**: ±30mm (configurável)
- **Rotação Roll, Pitch, Yaw**: ±8° (configurável)
- **Z**: Fixo em 500mm por padrão

### Validação em Múltiplas Camadas

1. **Frontend**: Clamp de valores antes de enviar
2. **Backend**: Clamp novamente + validação de cinemática inversa
3. **ESP32**: Limites de curso (500-680mm)

### Zona Morta

- Valores < 10% são zerados
- Previne drift e movimentos não intencionais

## 🔧 Configurações Avançadas

### Ajustar Limites

Edite em `app.py`:

```python
MAX_TRANS_MM = 30.0 
MAX_ANGLE_DEG = 8.0  
```

### Ajustar Taxa de Atualização

Edite em `joystick-control.js`:

```javascript
UPDATE_RATE_MS: 50,   // 20Hz (mais rápido = 30ms, mais lento = 100ms)
```

### Ajustar Zona Morta

```javascript
DEADZONE: 0.1,        // 10% (aumentar para 0.15 se houver drift)
```

## 🐛 Troubleshooting

### Gamepad não detectado

1. Certifique-se de que o gamepad está conectado
2. Pressione qualquer botão para "acordar" o gamepad
3. Verifique no console do navegador se há mensagens de conexão
4. Teste em outro navegador (Chrome recomendado)

### Preview 3D não atualiza

1. Verifique se o backend está rodando
2. Abra o console e procure por erros
3. Verifique se a URL da API está correta (`http://localhost:8001`)

### Comandos não aplicados no hardware

1. Certifique-se de que a serial está conectada
2. Verifique se "Aplicar no Hardware" está marcado
3. Verifique no console do backend se há mensagens de TX serial
4. A pose pode ser inválida (fora dos limites) - veja logs

### Movimentos muito sensíveis/insensíveis

Ajuste a zona morta ou os limites máximos conforme descrito acima

## 👤 Autor

**Guilherme Miyata** - Instituto Federal de São Paulo (IFSP)  
Trabalho de Conclusão de Curso - 2025

---

<a href='https://github.com/g-Miyata'>Github</a><br>
<a href='www.linkedin.com/in/g-miyata'>Linkedin</a><br>
<a href='https://www.g-miyata.com'>Portfólio</a>

**Última atualização:** Novembro 2025

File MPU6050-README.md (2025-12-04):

# Firmware MPU-6050 – Transmissor ESP-NOW

## Visão Geral

`esp32s3_codes/mpu-6050/mpu-6050.ino` é a versão simplificada do transmissor de orientação, baseada no módulo MPU6050 (MPU6050_light). Ele envia roll/pitch/yaw estimados para o ESP32-S3 principal via ESP-NOW e aceita comandos de recalibração remota, permitindo que o controlador redefina o zero sem acessar fisicamente o sensor.

## Fluxo Principal

1. **Setup**
   - Inicializa I2C (`Wire.begin(21, 22)`) e a biblioteca `MPU6050_light`.
   - Executa `mpu.calcOffsets()` com o sensor em repouso (o firmware instrui o usuário via Serial).
   - Configura ESP-NOW (`WiFi.mode(WIFI_STA)`, adiciona peer `receiverMac[]`, registra `onDataRecv`).

2. **Loop**
   - Chama `mpu.update()` continuamente.
   - A cada `sendIntervalMs` (50 ms ≈ 20 Hz), preenche `OrientationData` com `getAngleX/Y/Z()` e envia via `esp_now_send`.

3. **Recalibração**
   - `onDataRecv` recebe `OrientationData` vindo do ESP32-S3 principal.
   - Se `recalibra == true`, o firmware executa novamente `mpu.calcOffsets()` e escreve logs no Serial.

## Estrutura de Dados (ESP-NOW)

```cpp
typedef struct {
  float roll;
  float pitch;
  float yaw;
  bool  recalibra;
} OrientationData;
```

- `ori` – pacote enviado (roll/pitch/yaw atuais, `recalibra=false`).
- `recebido` – comando recebido (apenas `recalibra` é utilizado).

## Configurações Importantes

| Constante | Descrição |
| --- | --- |
| `receiverMac[]` | MAC do ESP32-S3 receptor (ajuste para o seu hardware). |
| `sendIntervalMs` | Intervalo entre envios (50 ms). |
| Pinos I2C | `Wire.begin(21, 22)` – troque conforme o módulo. |

## Integração com o Sistema

- Os dados enviados por este firmware chegam ao controlador principal (firmware PID) e são repassados ao backend via telemetria serial/WebSocket. Assim, páginas como `accelerometer.html` e `actuators.html` exibem os ângulos em tempo real.
- O backend/UX pode solicitar uma nova calibração (botão “Recalibrar” na interface). Esse comando percorre: UI → backend → firmware PID → ESP-NOW → este transmissor.

## Passos de Teste

1. Compile/flash `mpu-6050.ino` com a biblioteca `MPU6050_light` instalada.
2. No Serial Monitor (115200), confirme:
   - Status `MPU6050 status: 0`.
   - Mensagem “Calibração concluída!”.
   - MAC do transmissor e log “ESP-NOW pronto. Enviando ângulos...”.
3. Mova o sensor e observe os logs `Send -> R:...` para garantir que os pacotes estão sendo transmitidos.

## Arquivos Relacionados

- [PID-CONTROL-FILTER-SPIKE-BNO.md](PID-CONTROL-FILTER-SPIKE-BNO.md) – descreve como o ESP32-S3 controlador consome os dados do MPU6050 (quando não há BNO085).
- [ACCELEROMETER-README.md](ACCELEROMETER-README.md) – interface que exibe roll/pitch/yaw recebidos deste firmware.

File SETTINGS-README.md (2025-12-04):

# Painel de Configurações PID - Plataforma de Stewart

## Visão Geral

`settings.html` oferece uma tela enxuta para visualizar o estado da conexão e ajustar rapidamente os parâmetros de controle PID aplicados no firmware (ganhos Kp/Ki/Kd por pistão, valores globais, deadband em mm e PWM mínimo). O script `settings.js` consome os endpoints `/pid/gains` e `/pid/settings` do backend FastAPI e fornece feedback imediato via Toastify.

## Características

- Status da porta serial compartilhado com o restante da interface: o painel mostra LED, texto e porta detectada sem duplicar lógica (consulta periódica a `/serial/status`).
- Grade responsiva com cartões para cada pistão (Kp/Ki/Kd + botão “Aplicar”).
- Bloco “Todos os Pistões” para replicar um conjunto de ganhos em uma única chamada.
- Sessão “Parâmetros Globais” com campos para `dbmm` (deadband) e `minpwm`.
- Toasts coloridos para sucesso/erro e validação básica (parseFloat/parseInt).
- Carregamento automático dos valores atuais ao abrir a página.

## Arquitetura

### Backend (`interface/backend/app.py`)

- `GET /serial/status`: informa `connected` e `port`. O painel usa para exibir o LED e sincronizar `localStorage`.
- `GET /pid/gains`: devolve um dicionário `{1: {kp,ki,kd}, ...}` usado para preencher todos os inputs.
- `POST /pid/gains`: recebe `{ piston, kp, ki, kd }` para atualizar apenas um eixo.
- `POST /pid/gains/all`: aceita query parameters `kp`, `ki`, `kd` e replica para os seis pistões.
- `GET /pid/settings` / `POST /pid/settings`: leitura/escrita de `dbmm` e `minpwm`.

### Frontend (`settings.html` + `settings.js`)

- `updateConnectionStatus()`:
  - Chama `/serial/status` a cada 2 s.
  - Atualiza `status-indicator`, texto e porta.
  - Replica o estado no `localStorage` (para outras páginas usarem).
- `loadPIDGains()`:
  - `fetch('/pid/gains')`.
  - Preenche inputs `kp-x`, `ki-x`, `kd-x`.
  - Também usa os valores do pistão 1 para popular a seção “Todos os Pistões”.
- `loadPIDSettings()`:
  - `fetch('/pid/settings')`.
  - Atualiza inputs `dbmm` e `minpwm`.
- `sendGainsInd(piston)` / `sendGainsAll()`:
  - Realizam POST com JSON ou query string.
  - Mostram toasts de sucesso/erro conforme retorno.
- `sendSettings()`:
  - Envia JSON `{"dbmm": ..., "minpwm": ...}` e confirma com toast.

## Fluxo de Funcionamento

1. `DOMContentLoaded` → chama `updateConnectionStatus`, `loadPIDGains`, `loadPIDSettings`.
2. Usuário altera um ganho e pressiona “Aplicar” → `sendGainsInd` faz POST e aguarda resposta.
3. Toasts informam se o backend aceitou ou rejeitou valores.
4. A cada 2 s o painel checa o status da porta (mantém LED atualizado mesmo que outra página conecte/desconecte).

## Passo a Passo de Uso

1. Certifique-se de que o backend está em execução e o ESP32 conectado em alguma página (controller, actuators etc.) – o status será refletido aqui.
2. Abra `settings.html`.
3. Revise os valores carregados automaticamente em cada cartão.
4. Para atualizar um pistão:
   - Edite Kp/Ki/Kd.
   - Clique em “Aplicar”.
5. Para copiar ganhos iguais para todos:
   - Ajuste o bloco “Todos os Pistões”.
   - Clique em “Aplicar em Todos”.
6. Ajuste `dbmm` ou `minpwm` conforme a necessidade e clique em “Aplicar Ajustes”.

## Configurações Avançadas

- **Intervalo de polling**: mude o `setInterval(updateConnectionStatus, 2000)` para deixar o painel mais responsivo (ou economizar CPU).
- **Valores padrão**: os inputs começam com valores “dummy” (2.0/0.0). Pode-se alterar no HTML para refletir presets de fábrica.
- **Validação extra**: hoje o script apenas converte para `parseFloat/parseInt`. Adicione checagens e máscaras se desejar restringir faixas específicas.
- **Internacionalização**: a formatação de números usa o padrão americano (`.` como separador decimal). Caso queira vírgula, inclua um conversor no `sendGains*`.

## Troubleshooting

- **Toasts de erro “Erro ao aplicar ganhos”**:
  - Verifique se algum campo ficou vazio (retorna `NaN` no JSON).
  - Veja o terminal do backend para mensagens adicionais (ex.: pistão inexistente).
- **Valores não atualizam após salvar**:
  - Recarregue a página ou clique em algum botão “Aplicar” novamente – o backend pode ter ignorado por validação.
  - Confirme se o backend caiu (HTTP 500/422).
- **LED sempre vermelho**:
  - Mesmo com outra página conectada, se o backend estiver fora do ar o fetch falha → o script assume desconectado. Verifique `app.py`.
- **Inputs resetando sozinhos**:
  - `loadPIDGains` roda apenas no load inicial; se o backend enviar strings, podem aparecer valores `undefined`. Ajuste o endpoint para sempre mandar números.

## Autor

**Guilherme Miyata** - Instituto Federal de São Paulo (IFSP)  
Trabalho de Conclusão de Curso - 2025

---

<a href='https://github.com/g-Miyata'>Github</a><br>
<a href='www.linkedin.com/in/g-miyata'>Linkedin</a><br>
<a href='https://www.g-miyata.com'>Portfólio</a>

**Última atualização:** Novembro 2025

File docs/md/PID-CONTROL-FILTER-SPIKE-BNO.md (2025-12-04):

# Firmware PID com Filtro Anti-Spike (ESP32-S3)

## Visão Geral

`esp32s3_codes/pid-control-filter-spike-bno/pid-control-filter-spike-bno.ino` é o firmware responsável por fechar o loop dos seis atuadores lineares da plataforma de Stewart. Ele recebe a referência de posição via serial (em milímetros), lê o feedback analógico dos encoders lineares, aplica filtro anti-spike + mediana e gera comandos PWM com feedforward, anti-windup e compensações individuais. O mesmo firmware também escuta dados de orientação via ESP-NOW para exibir roll/pitch/yaw (MPU6050 ou BNO085) e usa esse canal para recalibração remota do sensor.

## Principais Recursos

- **Recepção ESP-NOW híbrida**: detecta automaticamente pacotes `OrientationData` (MPU6050 – roll/pitch/yaw) ou `TelemetryData` (BNO085 – inclui quaternions), mantendo os valores em variáveis voláteis.
- **Filtro anti-spike dinâmico** combinado com mediana-3 e média móvel (parametrizável) para suavizar os sinais de feedback.
- **PID por pistão** (`Kp/Ki/Kd` independentes) com feedforward assimétrico (`U0_adv/U0_ret`), offset de curso (mm) e deadband ajustável.
- **Controles manuais** via serial: seleção de pistão, avanço/recuo com PWM fixo ou “modo free” (IN1/IN2 em HIGH).
- **Calibração eletrônica**: cada canal possui par `V0/V100` e flag `hasCal`, permitindo mapear tensão (0–3.3V) para mm.
- **Telemetria CSV** contínua (33 ms) incluindo setpoint, posições reais, PWM aplicado e orientação (com ou sem quaternions).
- **Proteções internas**: limitação de integrador, anti-windup com tracking (`Tt_tracking`), PWM mínimo configurável e watchdog básico de serial.

## Arquitetura Geral

| Camada | Descrição |
| --- | --- |
| ESP-NOW RX (`setupEspNowReceiver`) | Configura o ESP32-S3 como STA, inicializa ESP-NOW e registra `onReceive`. Cada pacote recebido atualiza `oriRoll/Pitch/Yaw` e, no caso do BNO085, `oriQw/Qx/Qy/Qz`. |
| Aquisição analógica | `readFeedbackVoltages` realiza `analogRead` múltiplas vezes, salva no buffer para mediana e atualiza `fbV_raw`. |
| Filtragem | `filterFeedbackVoltage` aplica mediana-3, spike detection (rejeita valores que variam além de `SPIKE_THRESH` proporcional ao desvio) e média móvel (`MA_N`). Resultado em `fbV_filt`. |
| Conversão para mm | `voltsToMM` usa `V0/V100 + offset_mm` e saturação (`Lmm`) para obter `y_mm`. |
| Controle PID | Dentro da rotina principal (`loop`), para cada pistão calcula erro `e_mm`, derivada, integra com leak/anti-windup e gera PWM limitado. Feedforward assimétrico compensa zona morta. |
| Comandos manuais | Flags `manual_retract/manual_advance` permitem aplicar PWM fixo (`RETRACT_PWM/ADV_PWM`) apenas no pistão selecionado (`selIdx`). |
| Serial Parser | Aceita comandos textuais (`sel=`, `spmm=`, `spmm6x=`, `kpmm=`, etc.) separados por `\n`, atualizando o estado imediatamente. |
| Telemetria | A cada 33 ms imprime CSV com cabeçalho dinâmico (adiciona colunas de quaternions quando presentes). |

## Pinagem e PWM

- **Feedback analógico (`FB_PINS`)**: `{1, 2, 3, 4, 5, 6}` (use ADC1 para ruído menor).
- **PWM (`PWM_PINS`)**: `{8, 18, 9, 10, 11, 12}` usando LEDC (freq. 20 kHz, resolução 8 bits).
- **IN1/IN2 por pistão (`pistons[]`)**: `{{16, 17}, {13, 14}, {35, 36}, {21, 38}, {39, 37}, {41, 42}}` controla o sentido (avançar/recuar/free). Ex.: pistão 1 usa GPIO16/17.

## Principais Parametrizações

| Variável | Descrição |
| --- | --- |
| `Lmm[6]` | Curso útil de cada atuador (mm). |
| `SP_mm[6]` | Setpoint atual (mm). |
| `Kp_mm/Ki_mm/Kd_mm` | Ganhos PID individuais. |
| `U0_adv/U0_ret` | Feedforward para compensar zona morta em avanço/recuo. |
| `offset_mm` | Compensação fixa no feedback (ex.: +2 mm). |
| `deadband_mm` | Janela onde o PID desliga (mantém free e esvazia integrador). |
| `MIN_PWM` | PWM mínimo aplicado quando o controle exige movimento (evita ficar abaixo do atrito estático). |
| `T_leak`, `Tt_tracking`, `I_LIM` | Constantes de anti-windup e escoamento de integrador. |

## Comandos Serial

Todos os comandos são enviados via USB/Serial na forma `texto\n`.

| Comando | Função |
| --- | --- |
| `sel=X` | Seleciona pistão `1..6` para modo manual. |
| `spmm=VAL` | Define setpoint global (mm). |
| `spmm6x=v1,...,v6` | Define setpoints individuais. |
| `spmmN=VAL` | Define setpoint do pistão N (1-6). |
| `kpmm=idx,val` / `kimm=` / `kdmm=` | Ajusta ganho PID do pistão `idx`. |
| `kpall=VAL` / `kiall=` / `kdall=`  | Aplica o mesmo ganho em todos. |
| `dbmm=VAL` | Atualiza `deadband_mm`. |
| `lmm=idx,val` | Atualiza curso útil do pistão (ajusta saturação). |
| `fc=idx,v0,v100` | Atualiza calibração de tensão (`V0/V100`). |
| `minpwm=VAL` | Define PWM mínimo. |
| `vmaxmmps=VAL` | Limita derivada permitida (anti-spike). |
| `cal=idx` | Marca que o pistão `idx` possui calibração válida (`hasCal`). |
| `u0a=idx,val` / `u0r=idx,val` | Ajusta feedforward individual (avanço/recuo). |
| `u0aall=VAL` / `u0rall=VAL` | Ajuste em massa dos feedforward. |
| `offset=idx,val` / `offsetall=VAL` | Ajusta compensação em mm. |
| `man=adv` / `man=ret` / `man=free` | Ativa avanço, recuo ou libera modo manual. |
| `recalibra` | (Enviado via serial) Notifica o transmissor ESP-NOW para refazer o zero. |

## Fluxo Operacional

1. **Boot**: configura serial, PWM, leitura analógica, filtros e ESP-NOW (`setupEspNowReceiver`).
2. **Loop principal**:
   - Lê serial (`parseSerialCommand`), atualizando qualquer parâmetro.
   - Atualiza `dt` (baseado em `micros()`), lê tensões e filtra.
   - Calcula feedback em mm e aplica PID ou modo manual conforme flags.
   - Escreve PWM (`ledcWrite`) e define direção (`setDirAdvance/Return/Free`).
   - A cada 33 ms, imprime linha CSV com telemetria.
3. **ESP-NOW**: sempre que chega pacote, atualiza `oriRoll/Pitch/Yaw` (usados na telemetria) e guarda `lastSenderMac` para eventuais respostas.

## Exemplo de Telemetria (MPU6050)

```
ms;SP_mm;Y1;Y2;Y3;Y4;Y5;Y6;PWM1;PWM2;PWM3;PWM4;PWM5;PWM6;Roll;Pitch;Yaw
12345;10.000;9.85;10.12;9.97;9.90;9.88;10.01;80;75;78;82;79;81;1.24;-0.50;0.02
```

No caso do BNO085 o cabeçalho inclui `Qw,Qx,Qy,Qz` e a linha adiciona esses valores ao final.

## Dicas de Uso

1. **Calibração dos sensores lineares**: use `fc=idx,v0,v100` para cada pistão, depois `cal=idx` para marcar como válido. Sem essa etapa, `voltsToMM` pode saturar.
2. **Tunagem PID**: ajuste `Kp/Ki/Kd` via comandos individuais ou globais. O feedforward (`u0a/u0r`) ajuda a reduzir o esforço do PID quando os atuadores entram no regime não linear.
3. **Anti-spike**: se o ambiente estiver ruidoso, ajuste `SPIKE_THRESH_BASE/SPIKE_THRESH_PER_MM` (no início do arquivo) ou reduza `vmaxmmps` via serial para suavizar o filtro dinâmico.
4. **Telemetria**: use `pio device monitor` ou qualquer terminal serial configurado em 115200 baud para registrar os dados CSV. Importando em um spreadsheet fica fácil comparar setpoint vs. real.
5. **Integração com o backend**: o FastAPI envia `spmm6x=` com os cursos calculados. Certifique-se de usar a mesma unidade (mm).

## Estrutura do Projeto

```
esp32s3_codes/
└── pid-control-filter-spike-bno/
    ├── pid-control-filter-spike-bno.ino   ← firmware principal
    └── (demais arquivos gerados pela IDE, se houver)
```

## 👤 Autor

**Guilherme Miyata** - Instituto Federal de São Paulo (IFSP)  
Trabalho de Conclusão de Curso - 2025

---

<a href='https://github.com/g-Miyata'>Github</a><br>
<a href='www.linkedin.com/in/g-miyata'>Linkedin</a><br>
<a href='https://www.g-miyata.com'>Portfólio</a>

**Última atualização:** Novembro 2025

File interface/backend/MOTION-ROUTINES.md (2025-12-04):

# 🎬 Motor de Rotinas de Movimento - Stewart Platform

## 📋 Visão Geral

Sistema de execução de trajetórias senoidais automáticas para a plataforma Stewart, com controle via API REST e feedback em tempo real via WebSocket.

## ✨ Características

- **Execução em Thread Separada**: Não bloqueia o servidor FastAPI
- **Ramp-in/Ramp-out Suaves**: Transições suaves com curva cosseno (2s ou 20% da duração)
- **Validação Contínua**: Todas as poses são validadas pela cinemática inversa
- **Feedback em Tempo Real**: Eventos `motion_tick` via WebSocket a 60 Hz
- **Retorno Automático ao Home**: Ao parar, retorna suavemente para (0,0,h0,0,0,0)
- **Limites de Segurança**: Poses limitadas automaticamente

## 🎯 Rotinas Disponíveis

### 1. `sine_axis` - Movimento Senoidal em Um Eixo

Movimento senoidal puro em um eixo (x, y, z, roll, pitch, yaw).

**Parâmetros:**

- `axis` (obrigatório): `"x"`, `"y"`, `"z"`, `"roll"`, `"pitch"`, `"yaw"`
- `amp` (opcional): Amplitude
  - Padrão: 5 mm para eixos lineares (x,y,z)
  - Padrão: 2° para eixos angulares (roll,pitch,yaw)
- `offset` (opcional): Valor central
  - Padrão: 0 para x,y,roll,pitch,yaw
  - Padrão: h0 (432mm) para z
- `hz`: Frequência (padrão 0.2 Hz)
- `duration_s`: Duração (padrão 60s)

**Exemplo:**

```json
POST /motion/start
{
  "routine": "sine_axis",
  "axis": "z",
  "amp": 8,
  "hz": 0.3,
  "duration_s": 45
}
```

---

### 2. `circle_xy` - Círculo no Plano XY

Movimento circular (ou elíptico) no plano horizontal.

**Parâmetros:**

- `ax` (opcional): Raio X em mm (padrão: 10)
- `ay` (opcional): Raio Y em mm (padrão: 10)
- `phx` (opcional): Fase inicial em graus (padrão: 0)
- `hz`: Frequência de rotação (padrão 0.2 Hz)
- `duration_s`: Duração (padrão 60s)

**Exemplo:**

```json
POST /motion/start
{
  "routine": "circle_xy",
  "ax": 12,
  "ay": 8,
  "hz": 0.25,
  "duration_s": 60
}
```

---

### 3. `lissajous_xy` - Curva de Lissajous XY

Movimento complexo com frequências independentes em X e Y.

**Fórmulas:**

- x = ax · sin(2π·fx·t + phx)
- y = ay · sin(2π·fy·t + phy)

**Parâmetros:**

- `ax`, `ay` (opcional): Amplitudes em mm (padrão: 10, 6)
- `fx`, `fy` (opcional): Frequências independentes (padrão: hz, hz×1.5)
- `phx`, `phy` (opcional): Fases em graus (padrão: 0, 90)
- `duration_s`: Duração (padrão 60s)

**Exemplo:**

```json
POST /motion/start
{
  "routine": "lissajous_xy",
  "ax": 10,
  "ay": 6,
  "fx": 0.2,
  "fy": 0.3,
  "phx": 0,
  "phy": 90,
  "duration_s": 90
}
```

---

### 4. `heave_pitch` - Movimento Combinado Vertical + Pitch

Simula movimento de onda (heave + pitch com 90° de defasagem).

**Fórmulas:**

- z = h0 + amp · sin(2π·hz·t)
- pitch = ay · sin(2π·hz·t + 90°)

**Parâmetros:**

- `amp` (opcional): Amplitude vertical em mm (padrão: 8)
- `ay` (opcional): Amplitude de pitch em graus (padrão: 2.5)
- `hz`: Frequência (padrão 0.2 Hz)
- `duration_s`: Duração (padrão 60s)

**Exemplo:**

```json
POST /motion/start
{
  "routine": "heave_pitch",
  "amp": 8,
  "ay": 2.5,
  "hz": 0.2,
  "duration_s": 40
}
```

---

## 🛑 Controle de Execução

### Parar Rotina

```http
POST /motion/stop
```

Interrompe a rotina atual e retorna suavemente para home em ~1.5s.

**Resposta:**

```json
{
  "message": "Rotina parada"
}
```

---

### Consultar Status

```http
GET /motion/status
```

**Resposta:**

```json
{
  "running": true,
  "routine": "sine_axis",
  "params": {
    "routine": "sine_axis",
    "axis": "z",
    "amp": 8,
    "hz": 0.3,
    "duration_s": 45
  },
  "started_at": 1698765432.123,
  "elapsed": 12.456
}
```

---

## 📡 WebSocket - Eventos em Tempo Real

Conecte ao WebSocket `/ws/telemetry` para receber eventos:

### Evento `motion_tick`

Enviado a cada passo (60 Hz) durante a execução da rotina.

```json
{
  "type": "motion_tick",
  "t": 3.45,
  "pose_cmd": {
    "x": 0,
    "y": 0,
    "z": 440.0,
    "roll": 0,
    "pitch": 0,
    "yaw": 0
  },
  "routine": "sine_axis"
}
```

---

## 🔒 Limites de Segurança

Todas as poses são automaticamente limitadas:

| Parâmetro | Mínimo | Máximo |
| --- | --- | --- |
| x, y | -50 mm | +50 mm |
| z | h0-20 mm | h0+40 mm |
| roll, pitch, yaw | -10° | +10° |

Poses que violam os limites da cinemática inversa param a rotina automaticamente.

---

## 🧪 Exemplos de Teste

### 1. Seno em Z (básico)

```bash
curl -X POST http://localhost:8001/motion/start \
  -H "Content-Type: application/json" \
  -d '{
    "routine": "sine_axis",
    "axis": "z",
    "amp": 5,
    "hz": 0.2,
    "duration_s": 30
  }'
```

### 2. Círculo Elíptico

```bash
curl -X POST http://localhost:8001/motion/start \
  -H "Content-Type: application/json" \
  -d '{
    "routine": "circle_xy",
    "ax": 15,
    "ay": 10,
    "hz": 0.15,
    "duration_s": 60
  }'
```

### 3. Figura-8 (Lissajous com ratio 1:2)

```bash
curl -X POST http://localhost:8001/motion/start \
  -H "Content-Type: application/json" \
  -d '{
    "routine": "lissajous_xy",
    "ax": 12,
    "ay": 12,
    "fx": 0.2,
    "fy": 0.4,
    "phx": 0,
    "phy": 90,
    "duration_s": 120
  }'
```

### 4. Simulação de Onda Marítima

```bash
curl -X POST http://localhost:8001/motion/start \
  -H "Content-Type: application/json" \
  -d '{
    "routine": "heave_pitch",
    "amp": 10,
    "ay": 3,
    "hz": 0.25,
    "duration_s": 60
  }'
```

### 5. Parar Rotina

```bash
curl -X POST http://localhost:8001/motion/stop
```

### 6. Verificar Status

```bash
curl http://localhost:8001/motion/status
```

---

## ⚙️ Parâmetros Globais

| Parâmetro | Tipo  | Limites | Padrão |
| --- | ----- | --- | --- |
| `duration_s` | float | 0 < x ≤ 3600 | 60.0 |
| `hz` | float | 0 < x ≤ 2.0  | 0.2 |

---

## 🐛 Debug & Logs

O servidor imprime logs detalhados:

```
🎬 Rotina 'sine_axis' iniciada
▶️  Iniciando rotina 'sine_axis' por 45.0s @ 0.3Hz
✅ Rotina 'sine_axis' finalizada (2700 passos)
🏠 Retornando para home...
⏹️  Parando rotina...
```

Em caso de pose inválida:

```
❌ Pose inválida em t=12.34s: {'x': 0, 'y': 0, 'z': 550, ...}
```

---

## 🎓 Notas Técnicas

1. **Frequência de Atualização**: 60 Hz (dt = 16.67 ms)
2. **Espaçamento Serial**: 1.5 ms entre comandos `spmm1..6`
3. **Ramp Suave**: Curva cosseno para evitar jerks
4. **Thread Daemon**: Termina automaticamente com o servidor
5. **Event Loop**: Usa o loop do FastAPI para broadcast assíncrono

---
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

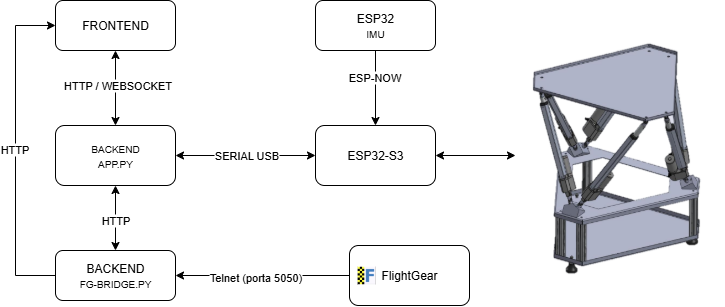
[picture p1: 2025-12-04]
interface/frontend/assets/mapa do sistema.png

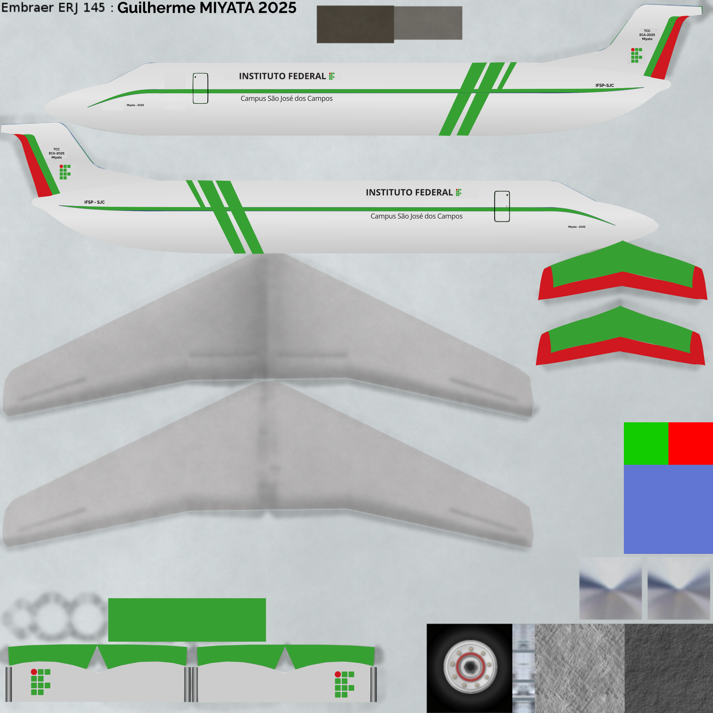
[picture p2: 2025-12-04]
interface/simulation/assets/ifsp-flightgear-livery.png

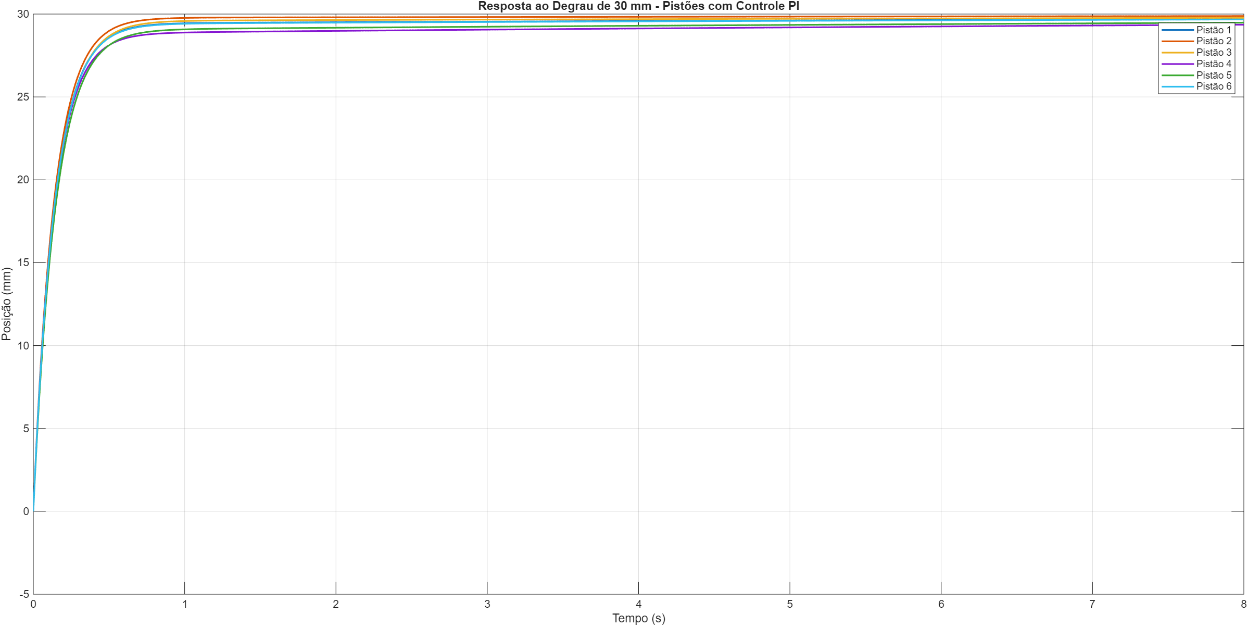
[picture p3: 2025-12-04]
MATLAB/control-system/before.png

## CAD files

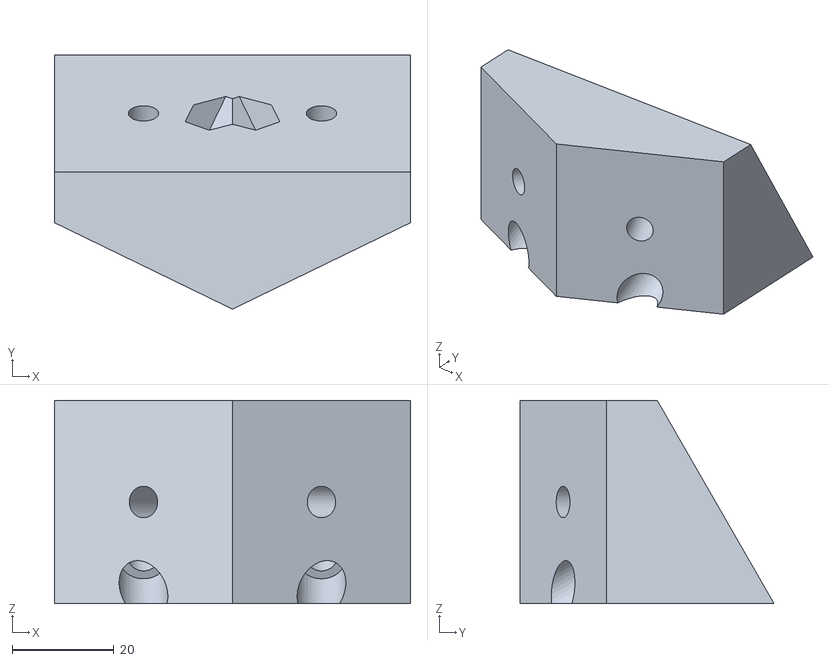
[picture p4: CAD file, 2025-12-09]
interface/web/dist/models/kardan-joint.stl
70.0 x 50.0 x 40.0

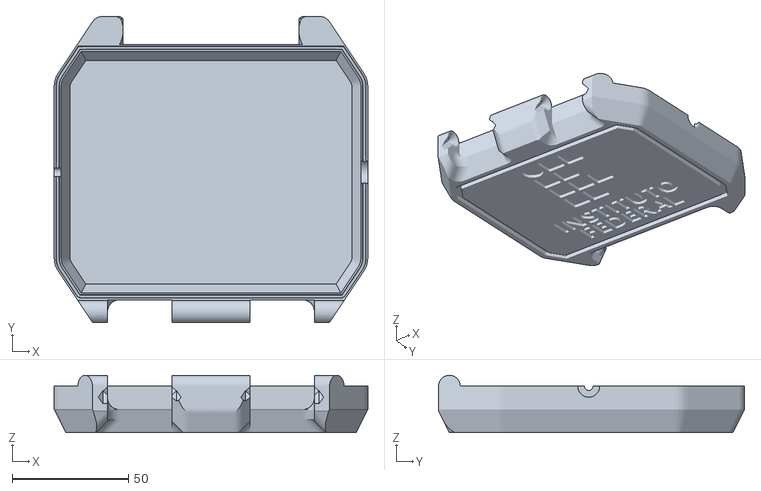
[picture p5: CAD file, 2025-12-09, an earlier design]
3D-drawings-archives/esp32-s3/Tampa.stl
135.0 x 131.7 x 24.7

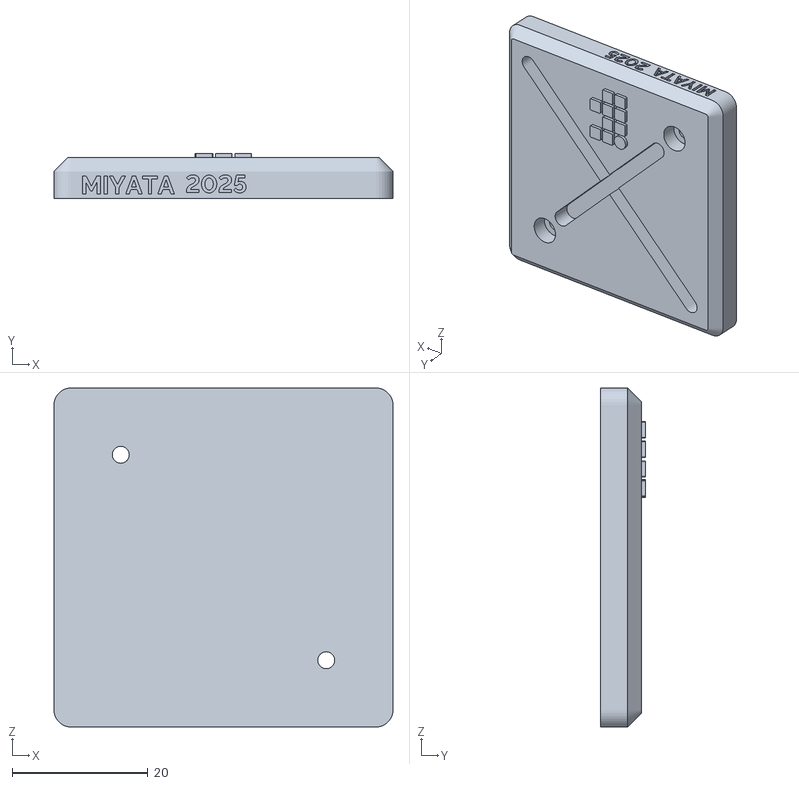
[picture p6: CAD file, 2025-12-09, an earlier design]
3D-drawings-archives/plane/base-encaixe.stl
50.0 x 6.60 x 50.0

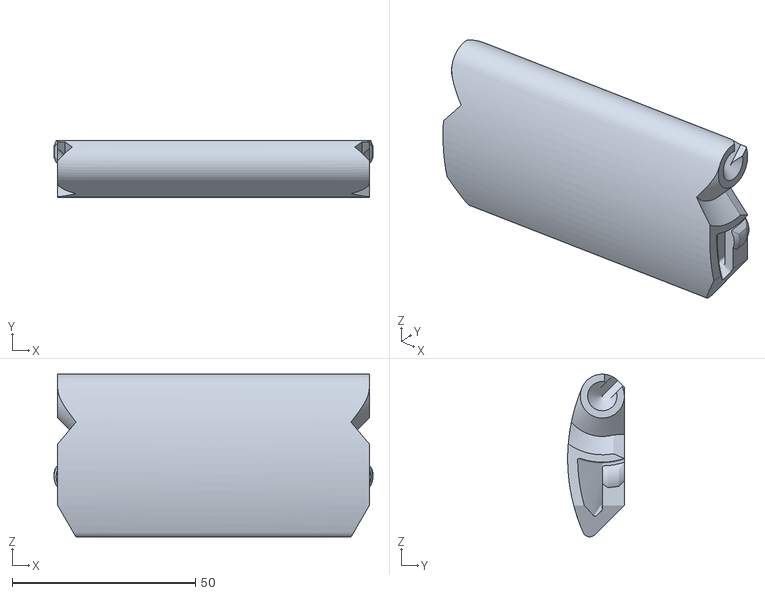
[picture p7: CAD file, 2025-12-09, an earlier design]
3D-drawings-archives/esp32-s3/trava.stl
87.0 x 15.4 x 44.4

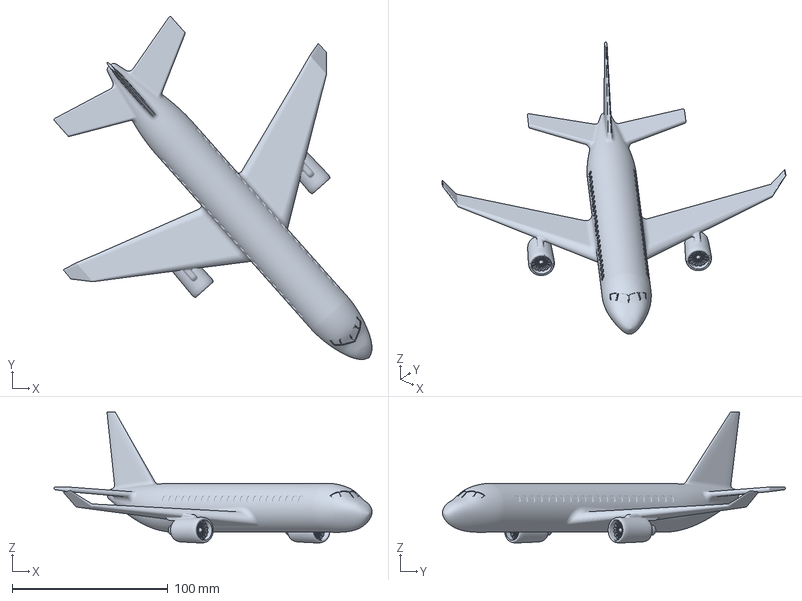
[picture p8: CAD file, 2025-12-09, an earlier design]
3D-drawings-archives/plane/Airliner.3mf
204.0 x 220.1 x 84.0 mm

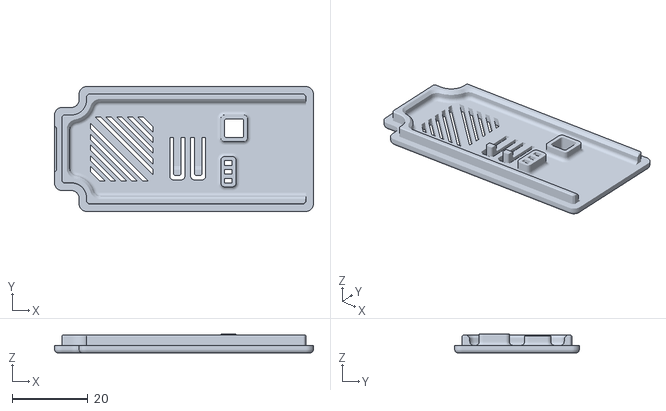
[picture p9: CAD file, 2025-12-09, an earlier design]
3D-drawings-archives/esp32-s3/caixa-esp32-s3-tampa.STL
68.5 x 33.0 x 5.00

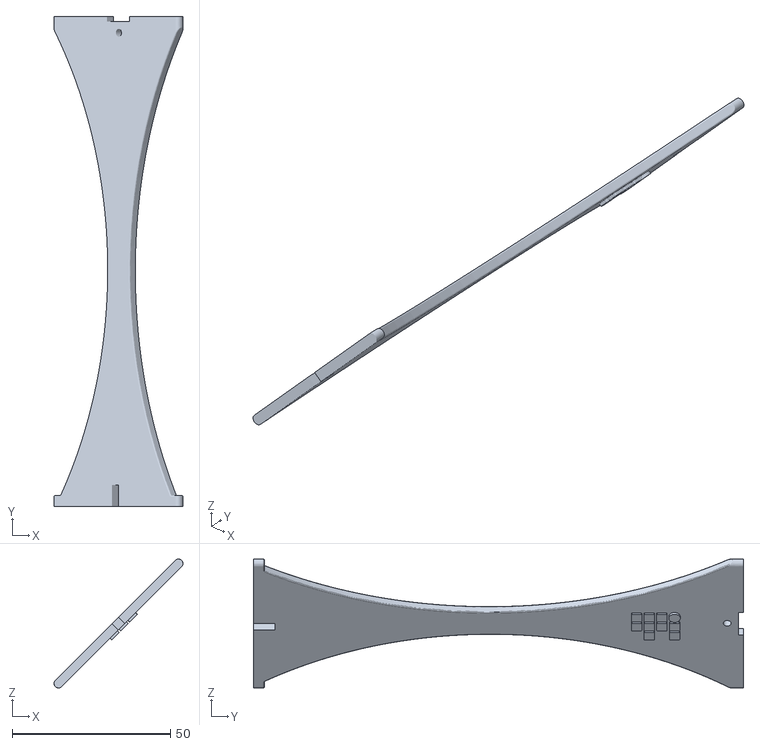
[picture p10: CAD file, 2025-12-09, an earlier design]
3D-drawings-archives/plane/haste.stl
40.8 x 155.0 x 40.8

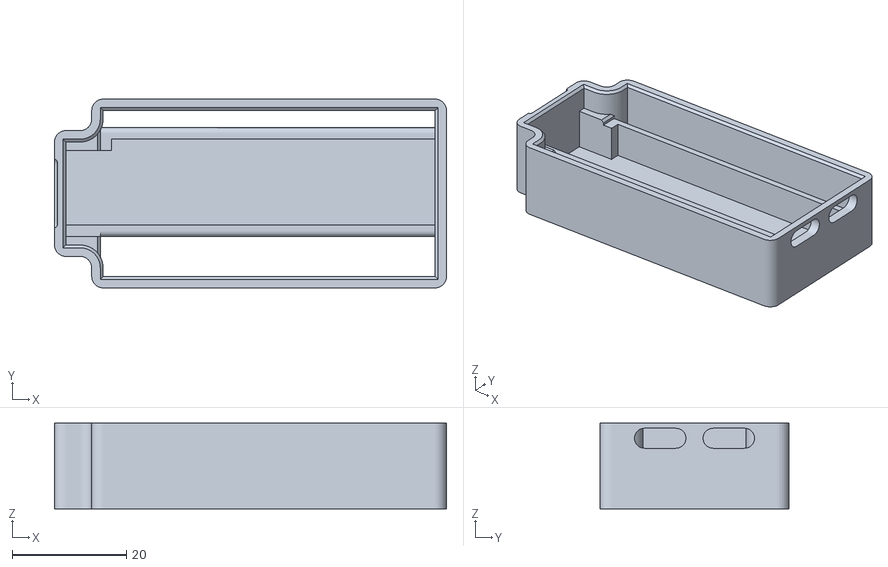
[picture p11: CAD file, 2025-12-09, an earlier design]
3D-drawings-archives/esp32-s3/caixa-esp32-s3.STL
68.5 x 33.0 x 15.0

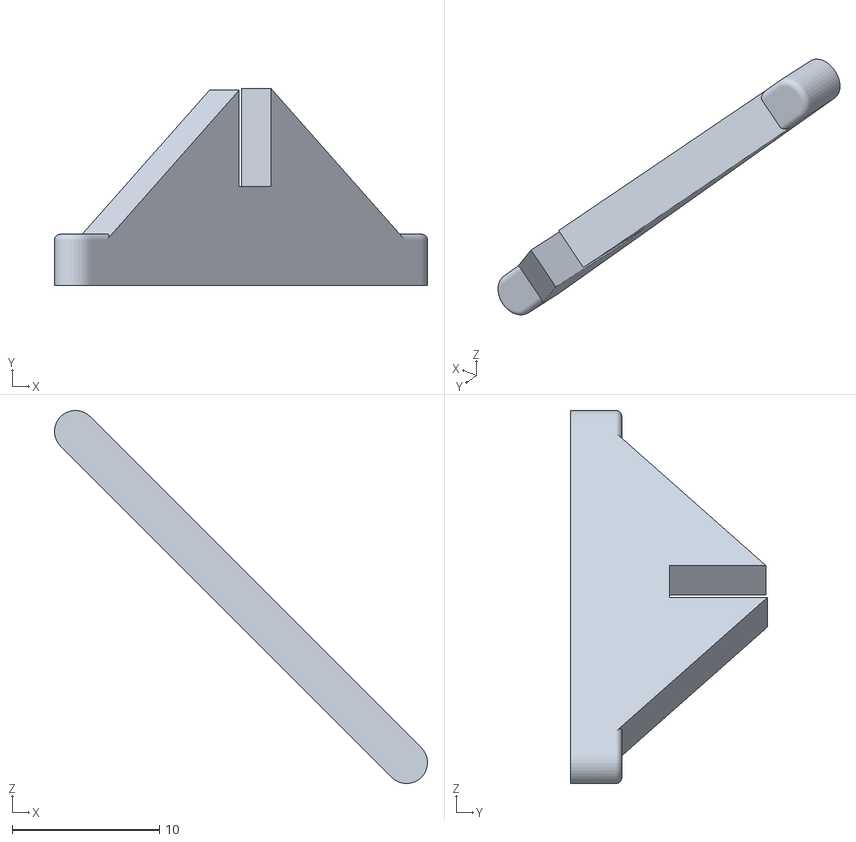
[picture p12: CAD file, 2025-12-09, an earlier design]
3D-drawings-archives/plane/suporte-base-x.STL
25.4 x 13.4 x 25.4

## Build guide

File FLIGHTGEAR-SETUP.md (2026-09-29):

# FlightGear: instalação e uso nas telas de voo

Este guia deixa o computador pronto para as telas **Simulador de voo** (`/simulador-voo`, motion cueing) e **Orientação do avião** (`/orientacao-voo`, roll/pitch). As duas usam o FlightGear de dois jeitos:

- **Rodar no FlightGear (voo gravado):** um botão na própria tela. O backend abre o FlightGear sem física, com o Embraer ERJ145 na pintura do IFSP, e o avião voa a gravação **sincronizado com a plataforma**. A imagem aparece dentro da página. É o modo para apresentações.
- **Voar ao vivo:** você (ou o piloto de demonstração) pilota o FlightGear com a física ligada, e a plataforma segue em tempo real. Também é assim que se gravam voos novos.

A tela antiga de roll/pitch por Telnet continua disponível só na interface `/antigo`.

## 1. Pré-requisitos

| O quê | Como instalar |
| --- | --- |
| FlightGear 2024.1 | `winget install FlightGear.FlightGear` (ou o instalador de [flightgear.org](https://www.flightgear.org/download/)) |
| Dados base (FGData) da mesma versão | Veja a seção 2 |
| Embraer ERJ145 | Veja a seção 3 |
| Backend do projeto | `start.bat`, ou o `README.md` principal |
| ~4 GB de memória livre | O FlightGear fecha sozinho quando a memória virtual acaba |

A pintura do IFSP (`interface/simulation/assets/ifsp.xml` e `ifsp-flightgear-livery.png`) é copiada para o avião **automaticamente**. Os protocolos UDP ficam no repositório, em `interface/simulation/fgdata/Protocol`, e não precisam ser copiados para lugar nenhum.

## 2. Dados base (FGData)

O instalador do FlightGear para Windows não traz os dados base. Na primeira vez que o FlightGear abre, o launcher baixa os arquivos um a um, o que é lento. É mais rápido baixar o pacote da mesma versão do binário (a do winget é a 2024.1.4) e extrair em `%USERPROFILE%\FlightGear`:

```bash
curl -L -o FlightGear-2024.1.4-data.txz https://mirrors.ibiblio.org/flightgear/ftp/release-2024.1/FlightGear-2024.1.4-data.txz
```

```bash
tar -xJf FlightGear-2024.1.4-data.txz -C "%USERPROFILE%\FlightGear"
```

A pasta resultante é `%USERPROFILE%\FlightGear\fgdata_2024_1`. O backend acha essa pasta sozinho; em outro lugar, defina a variável `FG_ROOT` com o caminho.

## 3. Avião ERJ145

1. Abra o FlightGear pelo atalho (o launcher gráfico).
2. Aba **Aircraft** → busque **ERJ** → **Embraer ERJ 145** → **Install**.
3. Feche o launcher.

O avião fica em `%USERPROFILE%\FlightGear\Downloads\Aircraft\org.flightgear.fgaddon.stable_2024\Aircraft\Embraer-ERJ-145`. Instalado à mão (zip do FGAddon), coloque a pasta `Embraer-ERJ-145` em `%USERPROFILE%\FlightGear\Custom Aircraft`, ou aponte `FG_AIRCRAFT` para a pasta que a contém.

## 4. Rodar um voo gravado no FlightGear (apresentação)

1. Suba o backend e abra **Simulador de voo** ou **Orientação do avião**.
2. No cartão **FlightGear**, confira **Pré-requisitos ok**. Se faltar algo, a lista mostra o item e como resolver (tabela da seção 6).
3. Clique em **Rodar no FlightGear**. A janela do FlightGear abre e, em 20 s a 1 min, a imagem aparece no cartão com o selo **No ar**.
4. Conecte a bancada (ou o **Simulador**) no topo da página e clique em **Engatar**.
5. Em **Voos gravados**, clique em **Play**. Voos com o selo "Aparece no FlightGear" são desenhados no FlightGear; a rotina pronta é **ERJ145 IFSP: decolagem, manobras e pouso em SBGR** (~6 min). Ela começa com uma apresentação do avião, com a câmera girando em volta e mostrando a pintura, e depois segue em terceira pessoa.

Dicas:
- **Imagem fluida:** a imagem que o FlightGear manda pelo servidor dele (MJPEG) tem ~7 fps e compressão JPEG. Para projetar, clique em **Imagem fluida (capturar a janela)** e escolha a janela do FlightGear na lista do navegador. A página passa a mostrar a janela em até 60 fps, na resolução real, e o FlightGear fica mais leve. Funciona no Chrome e no Edge; a escolha vale para as duas telas até você fechar o FlightGear ou clicar em "Voltar para a imagem do servidor".
- O ícone de tela cheia no canto da imagem serve para projetar.
- Deixe a janela do FlightGear aberta, mesmo atrás do navegador. Minimizada, ela para de desenhar e a imagem congela.
- Pausar, mudar a velocidade ou repetir o voo vale para a plataforma e para o avião ao mesmo tempo.
- Só uma tela manda na plataforma por vez. A outra mostra "engatada pela tela …" até você soltar por lá.

## 5. Voar ao vivo e gravar voos

```powershell
powershell -File interface\simulation\start-flightgear-cueing.ps1
```

```bash
cd interface\simulation
python fg-bridge.py --cueing
```

O primeiro comando abre o ERJ145 do IFSP no SBGR com a física ligada, a saída UDP a 60 Hz e a câmera de terceira pessoa. Por padrão, é meio-dia na pista 27R, a da rotina de demonstração. Sem isso, o FlightGear usa a hora real (à noite não se vê nada) e escolhe a pista pelo vento. Use `-TimeOfDay morning`, `-Runway 09L`, `-Aircraft c172p` (Cessna) ou `-View 0` (cabine) para mudar. O segundo repassa os dados ao backend.

Na aba **Ao vivo**, confira "Recebendo do FlightGear", engate e voe. **Gravar voo** salva em `interface/simulation/flights/`; voos gravados assim já trazem posição e superfícies para o botão do FlightGear.

Para o avião decolar e fazer as manobras sozinho (é assim que a rotina pronta foi gravada):

```bash
python fly-demo.py
```

## 6. Erros comuns

Os itens da lista de pré-requisitos têm estes identificadores (`GET /fg/check`):

| Item | Mensagem | Solução |
| --- | --- | --- |
| `fgfs` | fgfs não encontrado | Instale o FlightGear (`winget install FlightGear.FlightGear`) ou defina `FGFS` com o caminho completo do `fgfs.exe` |
| `fgdata` | FGData não encontrado ou de outra versão | Baixe o FGData da **mesma** versão do FlightGear (seção 2) ou defina `FG_ROOT` |
| `aircraft` | erj145-set.xml não encontrado | Instale o Embraer ERJ 145 pelo launcher (seção 3) ou aponte `FG_AIRCRAFT` |
| `livery` | Pintura ainda não copiada | Automático ao rodar. Se falhar por permissão, copie `assets/ifsp.xml` para `Embraer-ERJ-145\Models\Liveries` e o PNG para `Models\Liveries\2048x2048` |
| `protocols` | Protocolos faltando | Restaure `interface/simulation/fgdata/Protocol` do repositório |
| `ports` | TCP 8080 ou UDP 5511 em uso | Feche o outro FlightGear aberto (ou o programa na porta). Portas diferentes: variáveis `FG_HTTP_PORT` e `FG_VISUAL_PORT` antes de subir o backend |
| `memory` | Pouca memória livre (aviso) | Feche programas pesados (Blender, navegadores, IDEs). Com menos de ~4 GB livres, o FlightGear pode fechar no meio do voo |

Outras situações:

- **"O FlightGear fechou sozinho"**: o cartão mostra o código de saída e as últimas linhas de alerta do log (`%APPDATA%\flightgear.org\fgfs.log`). O caso mais comum é falta de memória. A plataforma continua tocando o voo.
- **"O FlightGear está aberto mas não responde"**: quase sempre é uma caixa de mensagem de erro na janela do FlightGear (por exemplo "Fatal exception"). Leia, feche e rode de novo.
- **Imagem preta ou congelada**: a janela do FlightGear está minimizada. Restaure (pode ficar atrás) e clique em **Recarregar imagem**.
- **Imagem travando ou com qualidade pior que a do FlightGear**: é o limite do MJPEG do FlightGear (~7 fps, JPEG). Use **Imagem fluida (capturar a janela)**.
- **Plataforma soltou sozinha**: o cartão **Eventos** mostra quem soltou (botão Soltar ou a página saindo da tela) e em qual aba. Fechar ou recarregar a aba dona da plataforma sempre solta, por segurança.
- **"Este voo foi gravado sem posição do avião"**: voos antigos (formato v1) movem a plataforma, mas não o FlightGear. Grave de novo pela aba Ao vivo.
- **Rodando `fgfs` no Git Bash**: o terminal converte argumentos que começam com `/` (`--prop:/sim/...` vira `C:/Program Files/Git/sim/...`) e o FlightGear para com "Illegal character in property path". Use o PowerShell, o `start-flightgear-cueing.ps1` ou o botão da tela.
- **ERJ145 com motores "sem combustível"** ao voar ao vivo: o avião abre com os tanques desmarcados. O `fly-demo.py` já marca os tanques e dá a partida; à mão, use o menu do avião (Autostart).

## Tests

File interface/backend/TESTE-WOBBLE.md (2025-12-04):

# 🧪 Guia de Teste - Wobble Precession

## Teste Rápido (5 minutos)

### 1. Inicie o servidor backend

```powershell
cd C:\Users\Miyata\Documents\ESP32S3\interface\backend
python app.py
```

Aguarde ver:

```
INFO:     Uvicorn running on http://0.0.0.0:8001 (Press CTRL+C to quit)
```

### 2. Execute os testes automatizados

Em **outro terminal**:

```powershell
cd C:\Users\Miyata\Documents\ESP32S3\interface\backend
python test_wobble.py
```

Pressione ENTER quando solicitado e aguarde os testes executarem.

**Resultado esperado:**

```
🎉 TODOS OS TESTES PASSARAM!
```

### 3. Teste no Frontend

1. Abra `C:\Users\Miyata\Documents\ESP32S3\interface\frontend\kinematics.html` no navegador

2. Role até a seção **"🎬 Rotinas de Movimento"**

3. Encontre o card **"🟡 Wobble Precession"** (último card, tema amarelo/amber)

4. Ajuste os parâmetros (ou use os defaults):

   - Tilt: 3.0°
   - Prec Hz: 0.4
   - Yaw Hz: 0.1
   - Z Amp: 6 mm
   - Z Phase: 90°
   - Duração: 40s (reduza para 10s para teste rápido)

5. Clique **"▶️ Iniciar"**

6. **Observe:**

   - ✅ Card fica com borda verde
   - ✅ Status muda para "🟢 Rodando"
   - ✅ Timer incrementa (00:01, 00:02, ...)
   - ✅ **Modelos 3D se movem** (Preview e Live)
   - ✅ Console do navegador (F12) mostra logs `🎬 Motion tick`

7. Clique **"⏹️ Parar"** ou aguarde terminar

8. **Observe:**
   - ✅ Status volta para "Parado"
   - ✅ Card volta ao normal (sem borda verde)
   - ✅ Timer reseta para 00:00
   - ✅ Modelos 3D retornam suavemente ao home

## Teste com Hardware (ESP32)

⚠️ **Requer plataforma Stewart física conectada**

1. Backend rodando (`python app.py`)

2. Abra `kinematics.html`

3. **Conecte ao ESP32:**

   - Selecione a porta COM
   - Clique "Abrir Serial"
   - Aguarde status "🟢 Conectado"

4. **Inicie wobble_precession:**

   - Ajuste parâmetros (comece com valores pequenos para segurança):
     - Tilt: 2.0° (reduzido)
     - Prec Hz: 0.3
     - Yaw Hz: 0.08
     - Z Amp: 4 mm (reduzido)
     - Duração: 15s
   - Clique "▶️ Iniciar"

5. **Observe a plataforma física:**

   - ✅ Inclinação precessa (vetor de tilt gira)
   - ✅ Rotação lenta em yaw
   - ✅ Oscilação vertical suave
   - ✅ Movimento coordenado dos 6 pistões

6. **Segurança:**
   - Mantenha mão no botão "⏹️ Parar"
   - Se movimento estranho, clique PARAR imediatamente
   - Plataforma deve retornar suavemente ao home

## Testes Avançados

### Teste 1: Wobble Lento (Hipnótico)

```json
{
  "routine": "wobble_precession",
  "duration_s": 60,
  "prec_hz": 0.25,
  "yaw_hz": 0.06,
  "tilt_deg": 2.5,
  "z_amp_mm": 5,
  "z_phase_deg": 90
}
```

**Efeito:** Movimento contemplativo, muito suave.

### Teste 2: Wobble Energético

```json
{
  "routine": "wobble_precession",
  "duration_s": 20,
  "prec_hz": 0.7,
  "yaw_hz": 0.18,
  "tilt_deg": 3.5,
  "z_amp_mm": 8,
  "z_phase_deg": 0
}
```

**Efeito:** Movimento dinâmico, Z sincronizado com inclinação.

### Teste 3: Wobble com Bias

```json
{
  "routine": "wobble_precession",
  "duration_s": 30,
  "prec_hz": 0.4,
  "yaw_hz": 0.1,
  "tilt_deg": 2.0,
  "tilt_bias_deg": 1.5,
  "z_amp_mm": 6,
  "z_phase_deg": 180
}
```

**Efeito:** Inclinação nunca volta a zero, Z em antifase.

### Teste 4: Z em Fase Diferente

Teste 3 fases diferentes e compare visualmente:

1. **Fase 0°** (sincronizado): Z máximo quando inclinação é máxima
2. **Fase 90°** (padrão): Z máximo quando inclinação passa por zero
3. **Fase 180°** (antifase): Z mínimo quando inclinação é máxima

## Troubleshooting

### ❌ Erro: "Pose inválida em t=0.00s"

**Causa:** Parâmetros violam limites cinemáticos desde o início.

**Solução:**

- Reduza `tilt_deg` para 2-3°
- Reduza `z_amp_mm` para 4-6mm
- Verifique que `tilt_bias_deg` + `tilt_deg` < 10°

### ❌ Rotina para após alguns segundos

**Causa:** Pose se torna inválida durante execução.

**Solução:**

- Reduza amplitudes
- Verifique logs do backend para ver qual pose falhou
- Teste com `duration_s` menor primeiro

### ❌ Modelos 3D não se movem

**Causa:** WebSocket não conectado ou eventos não sendo recebidos.

**Solução:**

1. Verifique console do navegador (F12)
2. Procure por erros de WebSocket
3. Confirme que backend está rodando
4. Recarregue a página

### ❌ "Connection refused" ao testar

**Causa:** Backend não está rodando.

**Solução:**

```powershell
cd C:\Users\Miyata\Documents\ESP32S3\interface\backend
python app.py
```

### ❌ Serial não conecta

**Causa:** Porta COM incorreta ou ESP32 desconectado.

**Solução:**

1. Clique "🔄 Atualizar Portas"
2. Verifique que ESP32 está conectado via USB
3. Selecione porta COM correta
4. Tente novamente

## Verificação de Sucesso

### ✅ Backend

- [ ] Servidor inicia sem erros
- [ ] `/motion/start` aceita `routine="wobble_precession"`
- [ ] `/motion/status` retorna `running=true` durante execução
- [ ] Logs mostram "🎬 Rotina 'wobble_precession' iniciada"
- [ ] Sem mensagens "❌ Pose inválida"

### ✅ Frontend

- [ ] Card "🟡 Wobble Precession" aparece
- [ ] Todos os 6 inputs são editáveis
- [ ] Botão "▶️ Iniciar" funciona
- [ ] Card fica verde ao iniciar
- [ ] Status mostra "Rodando"
- [ ] Timer incrementa
- [ ] Botão "⏹️ Parar" fica habilitado

### ✅ Visualização 3D

- [ ] Modelos 3D se movem durante rotina
- [ ] Movimento é suave (não "pula" frames)
- [ ] Preview e Live atualizam simultaneamente
- [ ] Console mostra logs "🎬 Motion tick"
- [ ] Modelos retornam ao home após parar

### ✅ Hardware (se conectado)

- [ ] Pistões se movem coordenadamente
- [ ] Movimento corresponde ao esperado
- [ ] Inclinação precessa visivelmente
- [ ] Yaw roda lentamente
- [ ] Z oscila suavemente
- [ ] Parar funciona corretamente
- [ ] Retorno ao home é suave (~1.5s)

## Métricas de Desempenho

### Backend

- **CPU Usage**: ~5-10% durante execução
- **Memory**: ~50-100 MB
- **WebSocket Rate**: 60 msg/s (motion_tick events)
- **Serial Rate**: ~400 commands/s (6 pistões × 60 Hz)

### Frontend

- **CPU Usage**: ~10-20% (visualização 3D)
- **Memory**: ~100-200 MB
- **Update Rate**: ~30 FPS (throttled de 60 Hz)
- **Latency**: <50ms (backend → frontend)

## Logs Esperados

### Backend (app.py)

```
▶️  Iniciando rotina 'wobble_precession' por 40.0s @ 0.4Hz
🎬 Rotina 'wobble_precession' iniciada
[movimento acontece silenciosamente]
✅ Rotina 'wobble_precession' finalizada (2400 passos)
🏠 Retornando para home...
```

### Frontend Console (F12)

```
🎬 Motion tick: {x: 0, y: 0, z: 503.2, roll: 2.1, pitch: -1.8, yaw: 14.4}
🎬 Motion tick: {x: 0, y: 0, z: 504.1, roll: 1.9, pitch: -2.0, yaw: 14.8}
...
```

## Próximos Experimentos

1. **Varie z_phase_deg** entre 0° e 360° (step 30°) e observe diferenças
2. **Compare prec_hz** lento (0.2) vs rápido (0.8)
3. **Teste tilt_bias_deg** diferentes: 0°, 1°, 2°
4. **Combine com baixo yaw_hz** (0.05) para movimento mais contemplativo
5. **Use z_hz = 2 \* prec_hz** para z oscilar duas vezes por revolução

## Documentação

- **Completa**: `WOBBLE-PRECESSION.md`
- **Resumo**: `WOBBLE-SUMMARY.md`
- **Código**: `app.py` (linhas 102-122, 633-665, 948-975)
- **Frontend**: `kinematics.html` (linhas 773-820, 1661)

---

**Implementado por:** Sistema de Motion Routines  
**Data:** 31 de Outubro de 2025  
**Status:** ✅ PRONTO PARA TESTES

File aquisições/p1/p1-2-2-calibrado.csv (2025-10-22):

hora | direcao | linha
22:09:57.400 | RX | 76099;0.000;0.000;0
22:09:57.511 | RX | 76199;0.000;0.000;0
22:09:57.621 | RX | 76299;0.000;0.000;0
22:09:57.622 | RX | 76399;0.000;0.000;0
22:09:57.728 | RX | 76499;0.000;0.000;0
22:09:57.838 | RX | 76599;0.000;0.000;0
22:09:57.949 | RX | 76699;0.000;0.000;0
22:09:58.056 | RX | 76799;0.000;0.000;0
22:09:58.166 | RX | 76899;0.000;0.000;0
22:09:58.278 | RX | 76999;0.000;0.000;0
22:09:58.388 | RX | 77099;0.000;0.000;0
22:09:58.499 | RX | 77199;0.000;0.000;0
22:09:58.610 | RX | 77299;0.000;0.000;0
22:09:58.721 | RX | 77399;0.000;0.000;0
22:09:58.722 | RX | 77499;0.000;0.000;0
22:09:58.827 | RX | 77599;0.000;0.000;0
22:09:58.932 | RX | 77699;0.000;0.000;0
22:09:59.037 | RX | 77799;0.000;0.000;0
22:09:59.142 | RX | 77899;0.000;0.000;0
22:09:59.246 | RX | 77999;0.000;0.000;0
22:09:59.351 | RX | 78100;0.000;0.000;0
22:09:59.460 | RX | 78199;0.000;0.000;0
22:09:59.565 | RX | 78299;0.000;0.000;0
22:09:59.670 | RX | 78399;0.000;0.000;0
22:09:59.781 | RX | 78499;0.000;0.000;0
22:09:59.890 | RX | 78599;0.000;0.000;0
22:09:59.995 | RX | 78699;0.000;0.000;0
22:10:00.100 | RX | 78799;0.000;0.000;0
22:10:00.205 | RX | 78899;0.000;0.000;0
22:10:00.317 | RX | 78999;0.000;0.000;0
22:10:00.429 | RX | 79099;0.000;0.000;0
22:10:00.429 | RX | 79199;0.000;0.000;0
22:10:00.538 | RX | 79299;0.000;0.000;0
22:10:00.645 | RX | 79400;0.000;0.000;0
22:10:00.750 | RX | 79499;0.000;0.000;0
22:10:00.855 | RX | 79599;0.000;0.000;0
22:10:00.960 | RX | 79699;0.000;0.000;0
22:10:01.065 | RX | 79799;0.000;0.000;0
22:10:01.170 | RX | 79899;0.000;0.000;0
22:10:01.278 | RX | 79999;0.000;0.000;0
22:10:01.390 | RX | 80099;0.000;0.000;0
22:10:01.498 | RX | 80199;0.000;0.000;0
22:10:01.603 | RX | 80299;0.000;0.000;0
22:10:01.713 | RX | 80399;30.000;0.000;66
22:10:01.825 | RX | 80499;30.000;0.481;65
22:10:01.827 | RX | 80599;30.000;0.928;64
22:10:01.937 | RX | 80699;30.000;2.255;61
22:10:02.042 | RX | 80800;30.000;1.859;62
22:10:02.148 | RX | 80899;30.000;4.101;57
22:10:02.254 | RX | 80999;30.000;4.787;55
22:10:02.364 | RX | 81100;30.000;5.555;54
22:10:02.468 | RX | 81199;30.000;6.712;51
22:10:02.573 | RX | 81299;30.000;7.772;49
22:10:02.680 | RX | 81399;30.000;9.003;46
22:10:02.789 | RX | 81499;30.000;8.561;47
22:10:02.898 | RX | 81599;30.000;9.634;45
22:10:03.003 | RX | 81700;30.000;9.702;45
22:10:03.108 | RX | 81799;30.000;10.309;43
22:10:03.215 | RX | 81899;30.000;11.070;42
22:10:03.318 | RX | 81999;30.000;11.259;41
22:10:03.429 | RX | 82099;30.000;11.468;41
22:10:03.431 | RX | 82199;30.000;12.326;39
22:10:03.539 | RX | 82299;30.000;12.775;38
22:10:03.651 | RX | 82399;30.000;13.181;37
22:10:03.761 | RX | 82499;30.000;13.333;37
22:10:03.873 | RX | 82599;30.000;14.247;35
22:10:03.984 | RX | 82699;30.000;13.707;36
22:10:04.097 | RX | 82799;30.000;14.100;35
22:10:04.210 | RX | 82899;30.000;15.137;33
22:10:04.320 | RX | 82999;30.000;14.824;33
22:10:04.427 | RX | 83099;30.000;14.946;33
22:10:04.429 | RX | 83199;30.000;16.003;31
22:10:04.534 | RX | 83299;30.000;16.397;30
22:10:04.638 | RX | 83399;30.000;16.548;30
22:10:04.746 | RX | 83499;30.000;16.589;30
22:10:04.852 | RX | 83599;30.000;16.767;29
22:10:04.957 | RX | 83699;30.000;16.982;29
22:10:05.062 | RX | 83799;30.000;17.184;28
22:10:05.169 | RX | 83899;30.000;17.160;28
22:10:05.276 | RX | 83999;30.000;17.520;27
22:10:05.384 | RX | 84099;30.000;17.804;27
22:10:05.488 | RX | 84199;30.000;17.862;27
22:10:05.593 | RX | 84299;30.000;19.542;23
22:10:05.705 | RX | 84399;30.000;17.483;28
22:10:05.817 | RX | 84499;30.000;17.950;27
22:10:05.928 | RX | 84599;30.000;16.973;29
22:10:05.930 | RX | 84699;30.000;17.730;27
22:10:06.033 | RX | 84799;30.000;17.315;28
22:10:06.140 | RX | 84899;30.000;18.075;26
22:10:06.248 | RX | 84999;30.000;17.715;27
22:10:06.354 | RX | 85099;30.000;18.303;26
22:10:06.462 | RX | 85199;30.000;18.534;25
22:10:06.571 | RX | 85299;30.000;18.724;25
22:10:06.684 | RX | 85399;30.000;18.634;25
22:10:06.795 | RX | 85499;30.000;17.939;27
22:10:06.907 | RX | 85599;30.000;18.393;26
22:10:07.012 | RX | 85699;30.000;18.492;25
22:10:07.118 | RX | 85799;30.000;18.318;26
22:10:07.225 | RX | 85899;30.000;18.254;26
22:10:07.228 | RX | 85999;30.000;18.357;26
22:10:07.332 | RX | 86100;30.000;18.287;26
22:10:07.437 | RX | 86199;30.000;18.434;25
22:10:07.542 | RX | 86299;30.000;18.351;26
22:10:07.647 | RX | 86400;30.000;17.948;27
22:10:07.752 | RX | 86499;30.000;17.625;27
22:10:07.857 | RX | 86599;30.000;18.191;26
22:10:07.963 | RX | 86699;30.000;18.569;25
22:10:08.074 | RX | 86799;30.000;18.117;26
22:10:08.185 | RX | 86899;30.000;17.849;27
22:10:08.296 | RX | 86999;30.000;17.366;28
22:10:08.407 | RX | 87099;30.000;18.241;26
22:10:08.517 | RX | 87199;30.000;18.592;25
22:10:08.622 | RX | 87299;30.000;18.678;25
22:10:08.625 | RX | 87399;30.000;18.418;25
22:10:08.742 | RX | 87499;30.000;18.451;25
22:10:08.847 | RX | 87599;30.000;18.331;26
22:10:08.953 | RX | 87699;30.000;18.732;25
22:10:09.058 | RX | 87799;30.000;18.089;26
22:10:09.163 | RX | 87899;30.000;18.157;26
22:10:09.272 | RX | 87999;30.000;18.080;26
22:10:09.378 | RX | 88099;30.000;18.033;26
22:10:09.489 | RX | 88199;30.000;17.948;27
22:10:09.600 | RX | 88299;30.000;18.234;26
22:10:09.709 | RX | 88399;30.000;18.266;26
22:10:09.820 | RX | 88499;30.000;18.383;26
22:10:09.930 | RX | 88599;30.000;18.423;25
22:10:09.932 | RX | 88699;30.000;18.561;25
22:10:10.039 | RX | 88799;30.000;19.899;22
22:10:10.147 | RX | 88899;30.000;18.415;25
22:10:10.256 | RX | 88999;30.000;18.940;24
22:10:10.364 | RX | 89099;30.000;17.995;26
22:10:10.472 | RX | 89199;30.000;18.434;25
22:10:10.578 | RX | 89299;30.000;17.845;27
22:10:10.687 | RX | 89399;30.000;18.350;26
22:10:10.793 | RX | 89499;30.000;18.083;26
22:10:10.898 | RX | 89599;30.000;18.267;26
22:10:11.004 | RX | 89699;30.000;18.418;25
22:10:11.108 | RX | 89799;30.000;18.282;26
22:10:11.215 | RX | 89899;50.000;17.991;70
22:10:11.318 | RX | 89999;50.000;19.414;67
22:10:11.428 | RX | 90099;50.000;20.373;65
22:10:11.431 | RX | 90199;50.000;21.666;62
22:10:11.537 | RX | 90299;50.000;22.841;60
22:10:11.648 | RX | 90399;50.000;23.039;59
22:10:11.757 | RX | 90499;50.000;23.284;59
22:10:11.868 | RX | 90599;50.000;25.505;54
22:10:11.981 | RX | 90700;50.000;26.151;52
22:10:12.092 | RX | 90799;50.000;27.284;50
22:10:12.203 | RX | 90899;50.000;27.304;50
22:10:12.314 | RX | 90999;50.000;28.899;46
22:10:12.426 | RX | 91099;50.000;28.618;47
22:10:12.428 | RX | 91199;50.000;29.491;45
22:10:12.537 | RX | 91299;50.000;30.636;43
22:10:12.646 | RX | 91399;50.000;30.539;43
22:10:12.753 | RX | 91499;50.000;31.063;42
22:10:12.858 | RX | 91599;50.000;32.138;39
22:10:12.964 | RX | 91699;50.000;32.449;39
22:10:13.069 | RX | 91799;50.000;32.958;37
22:10:13.178 | RX | 91899;50.000;33.726;36
22:10:13.287 | RX | 91999;50.000;33.332;37
22:10:13.393 | RX | 92099;50.000;34.091;35
22:10:13.499 | RX | 92199;50.000;34.301;35
22:10:13.608 | RX | 92299;50.000;34.728;34
22:10:13.715 | RX | 92399;50.000;33.585;36
22:10:13.822 | RX | 92499;50.000;33.843;36
22:10:13.824 | RX | 92599;50.000;35.002;33
22:10:13.927 | RX | 92699;50.000;35.785;31
22:10:14.032 | RX | 92799;50.000;36.085;31
22:10:14.137 | RX | 92899;50.000;35.744;31
22:10:14.242 | RX | 92999;50.000;36.846;29
22:10:14.347 | RX | 93099;50.000;36.943;29
22:10:14.452 | RX | 93199;50.000;37.414;28
22:10:14.557 | RX | 93299;50.000;37.506;27
22:10:14.665 | RX | 93399;50.000;38.006;26
22:10:14.776 | RX | 93499;50.000;38.283;26
22:10:14.882 | RX | 93599;50.000;38.441;25
22:10:14.987 | RX | 93699;50.000;38.172;26
22:10:15.092 | RX | 93799;50.000;39.165;24
22:10:15.199 | RX | 93899;50.000;38.785;25
22:10:15.310 | RX | 93999;50.000;39.070;24
22:10:15.419 | RX | 94099;50.000;38.765;25
22:10:15.527 | RX | 94199;50.000;38.814;25
22:10:15.529 | RX | 94299;50.000;39.082;24
22:10:15.632 | RX | 94399;50.000;39.283;24
22:10:15.738 | RX | 94499;50.000;39.119;24
22:10:15.847 | RX | 94599;50.000;39.237;24
22:10:15.958 | RX | 94699;50.000;38.636;25
22:10:16.068 | RX | 94799;50.000;38.409;25
22:10:16.177 | RX | 94899;50.000;39.016;24
22:10:16.289 | RX | 94999;50.000;39.258;24
22:10:16.401 | RX | 95099;50.000;39.303;24
22:10:16.511 | RX | 95199;50.000;39.825;22
22:10:16.618 | RX | 95299;50.000;39.130;24
22:10:16.727 | RX | 95399;50.000;39.734;23
22:10:16.729 | RX | 95499;50.000;39.622;23
22:10:16.833 | RX | 95599;50.000;39.783;22
22:10:16.938 | RX | 95699;50.000;39.008;24
22:10:17.043 | RX | 95799;50.000;39.468;23
22:10:17.148 | RX | 95899;50.000;39.040;24
22:10:17.257 | RX | 95999;50.000;38.944;24
22:10:17.362 | RX | 96099;50.000;38.086;26
22:10:17.467 | RX | 96199;50.000;38.965;24
22:10:17.572 | RX | 96299;50.000;39.183;24
22:10:17.677 | RX | 96399;50.000;39.409;23
22:10:17.783 | RX | 96499;50.000;39.370;23
22:10:17.892 | RX | 96599;50.000;38.911;24
22:10:17.997 | RX | 96699;50.000;39.010;24
22:10:18.102 | RX | 96799;50.000;39.329;23
22:10:18.210 | RX | 96899;50.000;38.814;25
22:10:18.313 | RX | 96999;50.000;38.340;26
22:10:18.418 | RX | 97099;50.000;38.911;24
22:10:18.523 | RX | 97199;50.000;39.028;24
22:10:18.526 | RX | 97299;50.000;38.694;25
22:10:18.628 | RX | 97399;50.000;38.942;24
22:10:18.736 | RX | 97499;50.000;40.362;21
22:10:18.845 | RX | 97599;50.000;39.336;23
22:10:18.952 | RX | 97699;50.000;39.654;23
22:10:19.061 | RX | 97799;50.000;38.670;25
22:10:19.172 | RX | 97899;50.000;39.488;23
22:10:19.280 | RX | 97999;50.000;39.859;22
22:10:19.391 | RX | 98099;50.000;39.223;24
22:10:19.504 | RX | 98199;50.000;40.166;22
22:10:19.616 | RX | 98299;50.000;39.127;24
22:10:19.727 | RX | 98399;50.000;39.442;23
22:10:19.729 | RX | 98499;50.000;39.548;23
22:10:19.832 | RX | 98599;50.000;40.102;22
22:10:19.938 | RX | 98699;50.000;39.563;23
22:10:20.045 | RX | 98799;50.000;39.379;23
22:10:20.152 | RX | 98899;50.000;39.761;23
22:10:20.258 | RX | 98999;50.000;39.267;24
22:10:20.367 | RX | 99099;50.000;39.211;24
22:10:20.479 | RX | 99199;50.000;39.341;23
22:10:20.583 | RX | 99299;50.000;39.818;22
22:10:20.688 | RX | 99400;50.000;39.669;23
22:10:20.793 | RX | 99499;50.000;39.817;22
22:10:20.898 | RX | 99599;50.000;39.558;23
22:10:21.005 | RX | 99699;50.000;39.663;23
22:10:21.108 | RX | 99799;50.000;39.579;23
22:10:21.215 | RX | 99899;50.000;39.299;24
22:10:21.324 | RX | 99999;50.000;39.369;23
22:10:21.328 | RX | 100099;50.000;39.648;23
22:10:21.443 | RX | 100200;50.000;39.631;23
22:10:21.548 | RX | 100299;50.000;39.209;24
22:10:21.653 | RX | 100399;50.000;40.543;21
22:10:21.758 | RX | 100499;50.000;39.132;24
22:10:21.867 | RX | 100599;50.000;39.676;23
22:10:21.979 | RX | 100699;50.000;39.781;22
22:10:22.090 | RX | 100799;50.000;39.645;23
22:10:22.200 | RX | 100899;50.000;39.398;23
22:10:22.311 | RX | 100999;50.000;39.953;22
22:10:22.417 | RX | 101099;50.000;40.154;22
22:10:22.522 | RX | 101199;50.000;39.781;22
22:10:22.527 | RX | 101299;120.000;39.359;177
22:10:22.632 | RX | 101399;120.000;40.759;174
22:10:22.739 | RX | 101499;120.000;45.200;165
22:10:22.851 | RX | 101599;120.000;49.642;155
22:10:22.957 | RX | 101699;120.000;52.748;148
22:10:23.062 | RX | 101799;120.000;55.517;142
22:10:23.172 | RX | 101899;120.000;59.035;134
22:10:23.280 | RX | 101999;120.000;61.502;129
22:10:23.385 | RX | 102099;120.000;64.357;122
22:10:23.490 | RX | 102199;120.000;66.895;117
22:10:23.597 | RX | 102299;120.000;68.848;113
22:10:23.702 | RX | 102399;120.000;71.427;107
22:10:23.807 | RX | 102499;120.000;73.677;102
22:10:23.912 | RX | 102599;120.000;76.085;97
22:10:24.017 | RX | 102699;120.000;78.491;91
22:10:24.127 | RX | 102799;120.000;80.790;86
22:10:24.129 | RX | 102899;120.000;82.017;84
22:10:24.232 | RX | 102999;120.000;82.454;83
22:10:24.337 | RX | 103099;120.000;84.699;78
22:10:24.442 | RX | 103199;120.000;87.472;72
22:10:24.547 | RX | 103299;120.000;88.628;69
22:10:24.652 | RX | 103399;120.000;89.882;66
22:10:24.761 | RX | 103499;120.000;91.575;63
22:10:24.868 | RX | 103599;120.000;92.649;60
22:10:24.974 | RX | 103699;120.000;92.857;60
22:10:25.079 | RX | 103799;120.000;93.369;59
22:10:25.183 | RX | 103899;120.000;94.993;55
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

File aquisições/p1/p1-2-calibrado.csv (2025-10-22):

hora | direcao | linha
21:19:41.667 | RX | ESP-ROM:esp32s3-20210327
21:19:41.668 | RX | Build:Mar 27 2021
21:19:41.668 | RX | rst:0x1 (POWERON),boot:0x8 (SPI_FAST_FLASH_BOOT)
21:19:41.669 | RX | SPIWP:0xee
21:19:41.670 | RX | mode:DIO, clock div:1
21:19:41.670 | RX | load:0x3fce3808,len:0x4bc
21:19:41.671 | RX | load:0x403c9700,len:0xbd8
21:19:41.671 | RX | load:0x403cc700,len:0x2a0c
21:19:41.672 | RX | entry 0x403c98d0
21:19:41.673 | RX | sep=;
21:19:41.674 | RX | ms;SP_mm;Y_mm;PWM
21:19:41.674 | RX | 99;0.000;0.000;0
21:19:41.787 | RX | 199;0.000;0.000;0
21:19:41.892 | RX | 299;0.000;0.000;0
21:19:42.002 | RX | 399;0.000;0.000;0
21:19:42.111 | RX | 499;0.000;0.000;0
21:19:42.222 | RX | 599;0.000;0.000;0
21:19:42.331 | RX | 699;0.000;0.000;0
21:19:42.443 | RX | 800;0.000;0.000;0
21:19:42.550 | RX | 899;0.000;0.000;0
21:19:42.660 | RX | 999;0.000;0.000;0
21:19:42.662 | RX | 1099;0.000;0.000;0
21:19:42.767 | RX | 1199;0.000;0.000;0
21:19:42.876 | RX | 1299;0.000;0.000;0
21:19:42.986 | RX | 1399;0.000;0.000;0
21:19:43.094 | RX | 1499;0.000;0.000;0
21:19:43.202 | RX | 1599;0.000;0.000;0
21:19:43.307 | RX | 1699;0.000;0.000;0
21:19:43.412 | RX | 1799;0.000;0.000;0
21:19:43.523 | RX | 1899;0.000;0.000;0
21:19:43.635 | RX | 1999;0.000;0.000;0
21:19:43.746 | RX | 2099;0.000;0.000;0
21:19:43.858 | RX | 2199;0.000;0.000;0
21:19:43.965 | RX | 2299;0.000;0.000;0
21:19:43.966 | RX | 2399;0.000;0.000;0
21:19:44.072 | RX | 2499;0.000;0.000;0
21:19:44.177 | RX | 2599;0.000;0.000;0
21:19:44.282 | RX | 2699;0.000;0.000;0
21:19:44.392 | RX | 2799;0.000;0.000;0
21:19:44.503 | RX | 2899;0.000;0.000;0
21:19:44.617 | RX | 2999;0.000;0.000;0
21:19:44.722 | RX | 3099;0.000;0.000;0
21:19:44.827 | RX | 3199;0.000;0.000;0
21:19:44.932 | RX | 3299;0.000;0.000;0
21:19:45.037 | RX | 3399;0.000;0.000;0
21:19:45.145 | RX | 3499;0.000;0.000;0
21:19:45.256 | RX | 3599;0.000;0.000;0
21:19:45.363 | RX | 3699;30.000;0.000;60
21:19:45.365 | RX | 3799;30.000;0.327;59
21:19:45.469 | RX | 3899;30.000;0.941;58
21:19:45.579 | RX | 3999;30.000;1.933;56
21:19:45.687 | RX | 4099;30.000;2.548;55
21:19:45.795 | RX | 4200;30.000;3.326;53
21:19:45.902 | RX | 4299;30.000;4.361;51
21:19:46.007 | RX | 4399;30.000;4.507;51
21:19:46.113 | RX | 4499;30.000;5.829;48
21:19:46.222 | RX | 4599;30.000;6.381;47
21:19:46.329 | RX | 4699;30.000;6.342;47
21:19:46.438 | RX | 4799;30.000;7.247;46
21:19:46.545 | RX | 4899;30.000;7.281;45
21:19:46.653 | RX | 4999;30.000;8.355;43
21:19:46.762 | RX | 5099;30.000;9.659;41
21:19:46.763 | RX | 5199;30.000;9.499;41
21:19:46.868 | RX | 5299;30.000;10.159;40
21:19:46.972 | RX | 5399;30.000;10.894;38
21:19:47.077 | RX | 5499;30.000;11.157;38
21:19:47.182 | RX | 5599;30.000;11.750;37
21:19:47.288 | RX | 5699;30.000;11.178;38
21:19:47.395 | RX | 5799;30.000;11.626;37
21:19:47.502 | RX | 5899;30.000;11.389;37
21:19:47.608 | RX | 5999;30.000;12.290;35
21:19:47.718 | RX | 6099;30.000;12.244;36
21:19:47.829 | RX | 6199;30.000;13.112;34
21:19:47.939 | RX | 6299;30.000;13.526;33
21:19:48.047 | RX | 6399;30.000;14.688;31
21:19:48.153 | RX | 6499;30.000;14.073;32
21:19:48.265 | RX | 6599;30.000;14.194;32
21:19:48.268 | RX | 6699;30.000;14.873;30
21:19:48.375 | RX | 6799;30.000;15.079;30
21:19:48.486 | RX | 6899;30.000;14.942;30
21:19:48.595 | RX | 6999;30.000;15.894;28
21:19:48.703 | RX | 7099;30.000;16.103;28
21:19:48.809 | RX | 7199;30.000;15.815;28
21:19:48.917 | RX | 7299;30.000;16.280;27
21:19:49.022 | RX | 7399;30.000;15.993;28
21:19:49.127 | RX | 7499;30.000;15.987;28
21:19:49.232 | RX | 7599;30.000;16.001;28
21:19:49.337 | RX | 7699;30.000;15.498;29
21:19:49.442 | RX | 7799;30.000;16.535;27
21:19:49.547 | RX | 7899;30.000;16.666;27
21:19:49.652 | RX | 7999;30.000;17.010;26
21:19:49.762 | RX | 8100;30.000;17.182;26
21:19:49.764 | RX | 8199;30.000;16.609;27
21:19:49.872 | RX | 8299;30.000;16.552;27
21:19:49.982 | RX | 8399;30.000;16.404;27
21:19:50.091 | RX | 8499;30.000;16.665;27
21:19:50.202 | RX | 8600;30.000;16.848;26
21:19:50.313 | RX | 8699;30.000;16.385;27
21:19:50.423 | RX | 8799;30.000;16.455;27
21:19:50.528 | RX | 8899;30.000;16.964;26
21:19:50.633 | RX | 9000;30.000;16.512;27
21:19:50.738 | RX | 9099;30.000;16.428;27
21:19:50.843 | RX | 9199;30.000;17.015;26
21:19:50.953 | RX | 9299;30.000;17.205;26
21:19:51.058 | RX | 9400;30.000;16.449;27
21:19:51.163 | RX | 9499;30.000;16.988;26
21:19:51.167 | RX | 9599;30.000;17.050;26
21:19:51.269 | RX | 9699;30.000;16.791;26
21:19:51.376 | RX | 9799;30.000;16.609;27
21:19:51.483 | RX | 9899;30.000;16.839;26
21:19:51.588 | RX | 9999;30.000;16.489;27
21:19:51.697 | RX | 10099;30.000;16.888;26
21:19:51.805 | RX | 10200;30.000;16.889;26
21:19:51.912 | RX | 10299;30.000;16.710;27
21:19:52.017 | RX | 10399;30.000;16.931;26
21:19:52.122 | RX | 10499;30.000;16.720;27
21:19:52.227 | RX | 10600;30.000;16.026;28
21:19:52.334 | RX | 10699;30.000;16.913;26
21:19:52.443 | RX | 10799;30.000;16.529;27
21:19:52.555 | RX | 10899;30.000;16.492;27
21:19:52.667 | RX | 10999;30.000;17.104;26
21:19:52.669 | RX | 11099;30.000;16.393;27
21:19:52.776 | RX | 11199;30.000;16.817;26
21:19:52.882 | RX | 11299;30.000;16.858;26
21:19:52.987 | RX | 11399;30.000;17.023;26
21:19:53.092 | RX | 11499;30.000;16.140;28
21:19:53.201 | RX | 11599;30.000;17.311;25
21:19:53.312 | RX | 11699;30.000;16.776;26
21:19:53.417 | RX | 11799;30.000;16.587;27
21:19:53.522 | RX | 11899;30.000;16.514;27
21:19:53.627 | RX | 11999;30.000;16.636;27
21:19:53.732 | RX | 12099;30.000;16.425;27
21:19:53.837 | RX | 12199;30.000;16.558;27
21:19:53.942 | RX | 12299;30.000;17.111;26
21:19:54.047 | RX | 12399;30.000;16.689;27
21:19:54.152 | RX | 12499;30.000;18.547;23
21:19:54.257 | RX | 12599;30.000;16.666;27
21:19:54.362 | RX | 12699;30.000;16.668;27
21:19:54.364 | RX | 12799;30.000;17.363;25
21:19:54.468 | RX | 12899;30.000;16.711;27
21:19:54.573 | RX | 12999;30.000;17.040;26
21:19:54.678 | RX | 13099;30.000;16.516;27
21:19:54.783 | RX | 13199;30.000;16.996;26
21:19:54.889 | RX | 13299;30.000;17.015;26
21:19:54.997 | RX | 13399;30.000;16.672;27
21:19:55.102 | RX | 13499;30.000;16.382;27
21:19:55.207 | RX | 13599;30.000;17.338;25
21:19:55.312 | RX | 13699;30.000;16.453;27
21:19:55.419 | RX | 13799;30.000;16.440;27
21:19:55.525 | RX | 13899;30.000;16.877;26
21:19:55.633 | RX | 13999;30.000;16.476;27
21:19:55.745 | RX | 14099;30.000;16.768;26
21:19:55.855 | RX | 14199;30.000;16.469;27
21:19:55.963 | RX | 14299;30.000;16.368;27
21:19:55.966 | RX | 14399;80.000;17.158;126
21:19:56.068 | RX | 14499;80.000;19.106;122
21:19:56.173 | RX | 14599;80.000;21.581;117
21:19:56.278 | RX | 14699;80.000;24.638;111
21:19:56.385 | RX | 14799;80.000;26.217;108
21:19:56.492 | RX | 14899;80.000;27.545;105
21:19:56.597 | RX | 14999;80.000;29.609;101
21:19:56.702 | RX | 15099;80.000;31.420;97
21:19:56.807 | RX | 15199;80.000;33.828;92
21:19:56.912 | RX | 15299;80.000;35.499;89
21:19:57.018 | RX | 15399;80.000;37.645;85
21:19:57.127 | RX | 15499;80.000;38.270;83
21:19:57.233 | RX | 15599;80.000;39.960;80
21:19:57.341 | RX | 15700;80.000;41.371;77
21:19:57.451 | RX | 15799;80.000;43.197;74
21:19:57.558 | RX | 15899;80.000;44.651;71
21:19:57.666 | RX | 15999;80.000;45.208;70
21:19:57.670 | RX | 16099;80.000;45.944;68
21:19:57.773 | RX | 16199;80.000;47.639;65
21:19:57.877 | RX | 16299;80.000;49.370;61
21:19:57.983 | RX | 16399;80.000;49.988;60
21:19:58.089 | RX | 16499;80.000;51.240;58
21:19:58.198 | RX | 16599;80.000;51.352;57
21:19:58.309 | RX | 16699;80.000;53.100;54
21:19:58.414 | RX | 16799;80.000;53.783;52
21:19:58.522 | RX | 16900;80.000;54.352;51
21:19:58.627 | RX | 16999;80.000;55.602;49
21:19:58.732 | RX | 17099;80.000;55.696;49
21:19:58.841 | RX | 17199;80.000;56.850;46
21:19:58.947 | RX | 17299;80.000;57.183;46
21:19:59.052 | RX | 17399;80.000;57.350;45
21:19:59.157 | RX | 17499;80.000;58.823;42
21:19:59.262 | RX | 17599;80.000;59.160;42
21:19:59.264 | RX | 17699;80.000;59.924;40
21:19:59.367 | RX | 17799;80.000;60.037;40
21:19:59.473 | RX | 17899;80.000;61.511;37
21:19:59.584 | RX | 18000;80.000;60.701;39
21:19:59.692 | RX | 18099;80.000;61.509;37
21:19:59.802 | RX | 18199;80.000;62.486;35
21:19:59.908 | RX | 18299;80.000;62.407;35
21:20:00.013 | RX | 18399;80.000;63.774;32
21:20:00.119 | RX | 18499;80.000;63.673;33
21:20:00.223 | RX | 18599;80.000;63.872;32
21:20:00.328 | RX | 18699;80.000;65.306;29
21:20:00.433 | RX | 18799;80.000;64.464;31
21:20:00.539 | RX | 18899;80.000;64.859;30
21:20:00.648 | RX | 18999;80.000;65.259;29
21:20:00.753 | RX | 19099;80.000;66.355;27
21:20:00.863 | RX | 19199;80.000;65.532;29
21:20:00.867 | RX | 19299;80.000;65.260;29
21:20:00.983 | RX | 19399;80.000;64.893;30
21:20:01.088 | RX | 19499;80.000;66.304;27
21:20:01.198 | RX | 19599;80.000;65.577;29
21:20:01.303 | RX | 19699;80.000;66.890;26
21:20:01.408 | RX | 19799;80.000;66.309;27
21:20:01.514 | RX | 19899;80.000;67.127;26
21:20:01.622 | RX | 19999;80.000;67.193;26
21:20:01.727 | RX | 20099;80.000;67.104;26
21:20:01.832 | RX | 20199;80.000;67.600;25
21:20:01.938 | RX | 20299;80.000;66.934;26
21:20:02.046 | RX | 20399;80.000;67.009;26
21:20:02.152 | RX | 20499;80.000;68.106;24
21:20:02.258 | RX | 20599;80.000;68.188;24
21:20:02.362 | RX | 20699;80.000;67.046;26
21:20:02.364 | RX | 20799;80.000;67.506;25
21:20:02.467 | RX | 20899;80.000;67.538;25
21:20:02.572 | RX | 20999;80.000;68.715;23
21:20:02.679 | RX | 21099;80.000;67.843;24
21:20:02.788 | RX | 21199;80.000;68.591;23
21:20:02.899 | RX | 21299;80.000;68.705;23
21:20:03.007 | RX | 21399;80.000;68.254;23
21:20:03.113 | RX | 21499;80.000;68.556;23
21:20:03.218 | RX | 21599;80.000;68.518;23
21:20:03.323 | RX | 21699;80.000;67.316;25
21:20:03.429 | RX | 21799;80.000;67.742;25
21:20:03.534 | RX | 21899;80.000;68.735;23
21:20:03.642 | RX | 21999;80.000;68.217;24
21:20:03.747 | RX | 22099;80.000;68.712;23
21:20:03.852 | RX | 22199;80.000;69.656;21
21:20:03.957 | RX | 22299;80.000;68.543;23
21:20:04.065 | RX | 22399;80.000;69.237;22
21:20:04.067 | RX | 22499;80.000;68.339;23
21:20:04.172 | RX | 22599;80.000;69.486;21
21:20:04.282 | RX | 22699;80.000;68.712;23
21:20:04.387 | RX | 22800;80.000;68.150;24
21:20:04.492 | RX | 22899;80.000;67.164;26
21:20:04.597 | RX | 22999;80.000;68.921;22
21:20:04.708 | RX | 23099;80.000;68.458;23
21:20:04.817 | RX | 23199;80.000;68.904;22
21:20:04.925 | RX | 23299;80.000;69.400;21
21:20:05.032 | RX | 23399;80.000;69.552;21
21:20:05.138 | RX | 23499;80.000;68.749;23
21:20:05.247 | RX | 23599;150.000;71.394;157
21:20:05.357 | RX | 23699;150.000;74.604;151
21:20:05.467 | RX | 23800;150.000;77.308;145
21:20:05.471 | RX | 23899;150.000;81.122;138
21:20:05.573 | RX | 23999;150.000;83.568;133
21:20:05.682 | RX | 24099;150.000;87.446;125
21:20:05.787 | RX | 24199;150.000;89.897;120
21:20:05.892 | RX | 24299;150.000;91.691;117
21:20:05.997 | RX | 24399;150.000;94.344;111
21:20:06.102 | RX | 24499;150.000;96.586;107
21:20:06.213 | RX | 24599;150.000;97.841;104
21:20:06.320 | RX | 24699;150.000;100.694;99
21:20:06.427 | RX | 24799;150.000;103.543;93
21:20:06.532 | RX | 24899;150.000;103.211;94
21:20:06.637 | RX | 24999;150.000;106.539;87
21:20:06.745 | RX | 25099;150.000;108.786;82
21:20:06.856 | RX | 25199;150.000;109.422;81
21:20:06.968 | RX | 25299;150.000;112.017;76
21:20:06.970 | RX | 25399;150.000;113.388;73
21:20:07.078 | RX | 25499;150.000;114.075;72
21:20:07.189 | RX | 25599;150.000;116.699;67
21:20:07.298 | RX | 25699;150.000;116.739;67
21:20:07.403 | RX | 25799;150.000;118.474;63
21:20:07.513 | RX | 25899;150.000;119.409;61
21:20:07.623 | RX | 25999;150.000;121.495;57
21:20:07.733 | RX | 26099;150.000;121.548;57
21:20:07.839 | RX | 26199;150.000;121.914;56
21:20:07.948 | RX | 26300;150.000;123.630;53
21:20:08.058 | RX | 26399;150.000;125.311;49
21:20:08.163 | RX | 26499;150.000;126.170;48
21:20:08.166 | RX | 26599;150.000;126.478;47
21:20:08.272 | RX | 26699;150.000;126.654;47
21:20:08.382 | RX | 26799;150.000;125.564;49
21:20:08.487 | RX | 26899;150.000;127.953;44
21:20:08.593 | RX | 26999;150.000;129.421;41
21:20:08.703 | RX | 27099;150.000;128.794;42
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

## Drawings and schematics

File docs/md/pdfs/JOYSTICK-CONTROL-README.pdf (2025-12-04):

JOYSTICK-CONTROL-README.md | 2025-12-04

# Sistema de Controle por Joystick - Plataforma de Stewart

## 📋 Visão Geral

Sistema completo de controle em tempo real da Plataforma de Stewart usando gamepad/joystick, integrado ao backend FastAPI e frontend Three.js.

## 🎮 Características

Controle em Tempo Real: Mapeamento direto dos eixos do joystick para translação/rotação da plataforma
Limites de Segurança: ±30mm de translação e ±8° de rotação (configuráveis)
Preview 3D em Tempo Real: Visualização instantânea da pose calculada
Modo Dual: Preview-only ou aplicação no hardware
Validação Automática: Verifica limites dos atuadores antes de aplicar

## 🕹 Mapeamento do Controle

Stick Esquerdo

Horizontal (LX): Translação em X (±30mm) Vertical (LY): Translação em Y (±30mm)
Stick Direito

Horizontal (RX): Rotação Pitch (±8°) Vertical (RY): Rotação Roll (±8°)
Triggers (Futuro)

LT/RT: não implementado ainda
Zona Morta

Valores menores que 0.1 (10%) são ignorados para evitar drift

## 🏗 Arquitetura

Backend (app.py)

Novo Modelo Pydantic

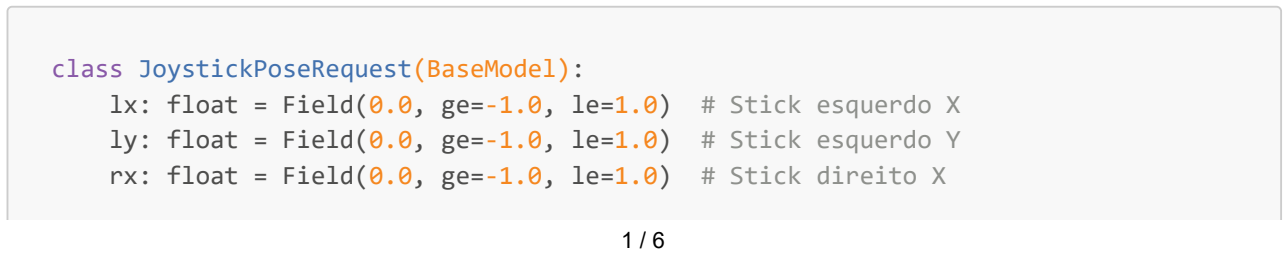
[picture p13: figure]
class JoystickPoseRequest(BaseModel):

lx: float = Field(0.0, ge=-1.0, le=1.0) # Stick esquerdo X ly: float = Field(0.0, ge=-1.0, le=1.0) # Stick esquerdo Y rx: float = Field(0.0, ge=-1.0, le=1.0) # Stick direito X

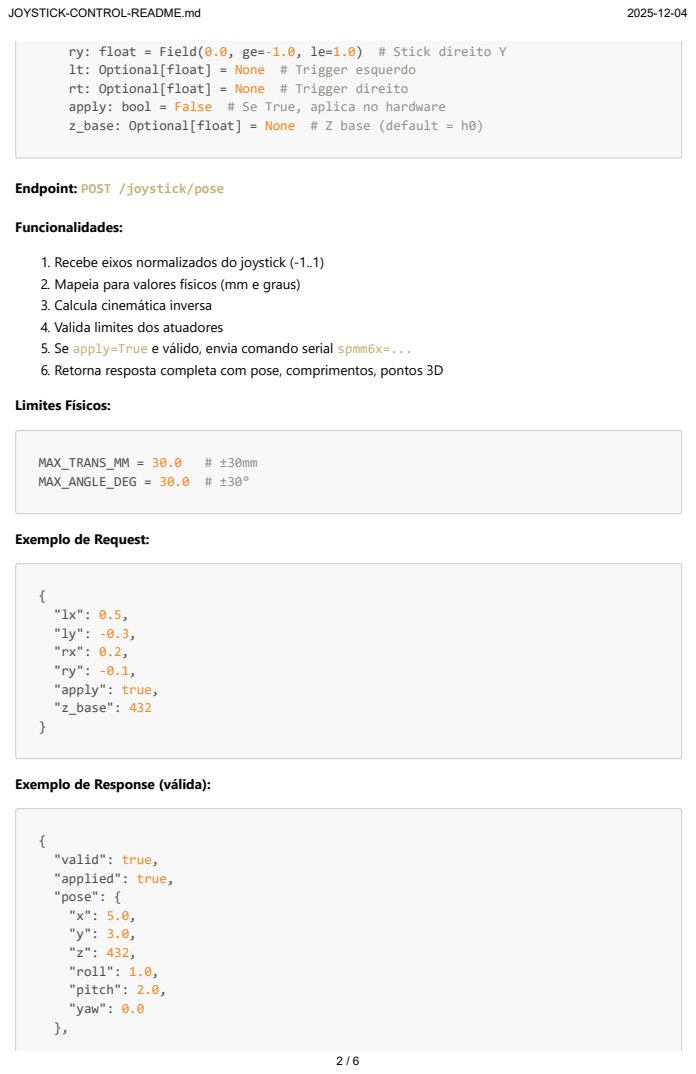
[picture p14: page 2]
Funcionalidades:; Limites Físicos:; MAX_TRANS_MM = 30.0; MAX_ANGLE_DEG = 30.0 # ±30°; "lx": 0.5, "ly": -0.3, "rx": 0.2, "ry": -0.1, "apply": true, "z_base": 432; "valid": true, "applied": true, "pose": { "x": 5.0, "y": 3.0, "z": 432, "roll": 1.0, "pitch": 2.0, "yaw": 0.0

ry: float = Field(0.0, ge=-1.0, le=1.0) # Stick direito Y
lt: Optional[float] = None # Trigger esquerdo
rt: Optional[float] = None # Trigger direito
apply: bool = False # Se True, aplica no hardware
z_base: Optional[float] = None # Z base (default = h0)

Endpoint: POST /joystick/pose

1. Recebe eixos normalizados do joystick (-1..1)
2. Mapeia para valores físicos (mm e graus)
3. Calcula cinemática inversa
4. Valida limites dos atuadores
5. Se apply=True e válido, envia comando serial spmm6x=...
6. Retorna resposta completa com pose, comprimentos, pontos 3D

Exemplo de Request:

Exemplo de Response (válida):

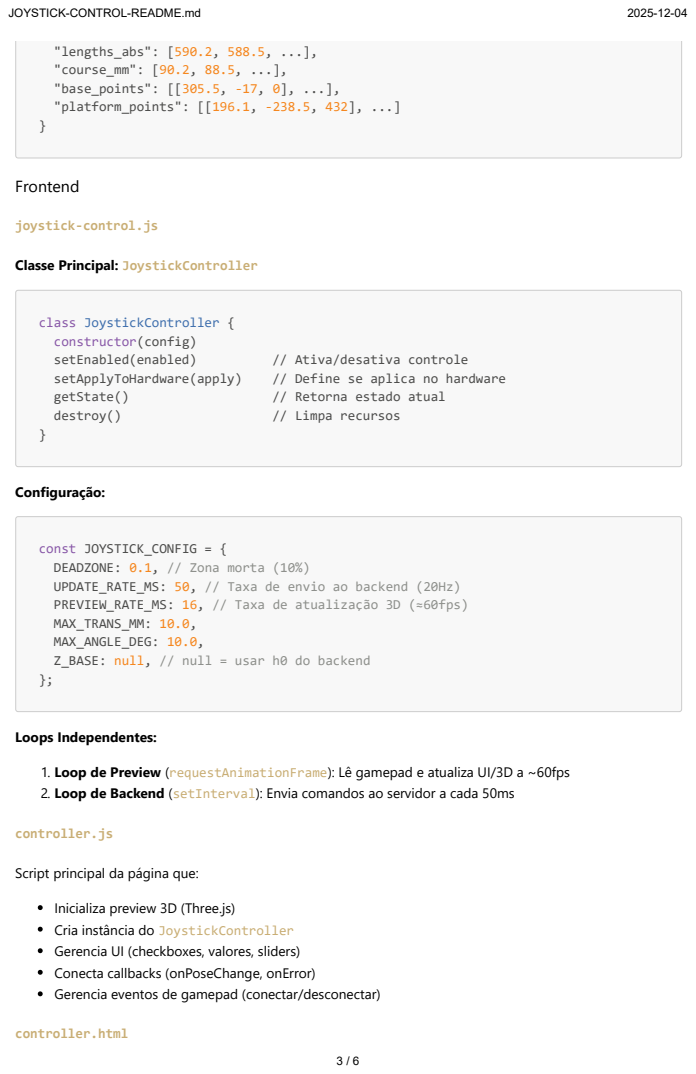
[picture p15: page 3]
"lengths_abs": [590.2, 588.5, ...], "course_mm": [90.2, 88.5, ...], "base_points": [[305.5, -17, 0], ...], "platform_points": [[196.1, -238.5, 432], ...]; Frontend; class JoystickController { constructor(config); setEnabled(enabled); // Ativa/desativa controle; setApplyToHardware(apply); // Define se aplica no hardware; getState(); // Retorna estado atual; destroy(); // Limpa recursos; Configuração:; Loops Independentes:; controller.js; controller.html

joystick-control.js

Classe Principal: JoystickController

const JOYSTICK_CONFIG = {
DEADZONE: 0.1, // Zona morta (10%)
UPDATE_RATE_MS: 50, // Taxa de envio ao backend (20Hz)
PREVIEW_RATE_MS: 16, // Taxa de atualização 3D (≈60fps)
MAX_TRANS_MM: 10.0,
MAX_ANGLE_DEG: 10.0,
Z_BASE: null, // null = usar h0 do backend

1. Loop de Preview (requestAnimationFrame): Lê gamepad e atualiza UI/3D a ~60fps
2. Loop de Backend (setInterval): Envia comandos ao servidor a cada 50ms

Script principal da página que:

Inicializa preview 3D (Three.js)
Cria instância do JoystickController
Gerencia UI (checkboxes, valores, sliders)
Conecta callbacks (onPoseChange, onError)
Gerencia eventos de gamepad (conectar/desconectar)

## 🚀 Como Usar

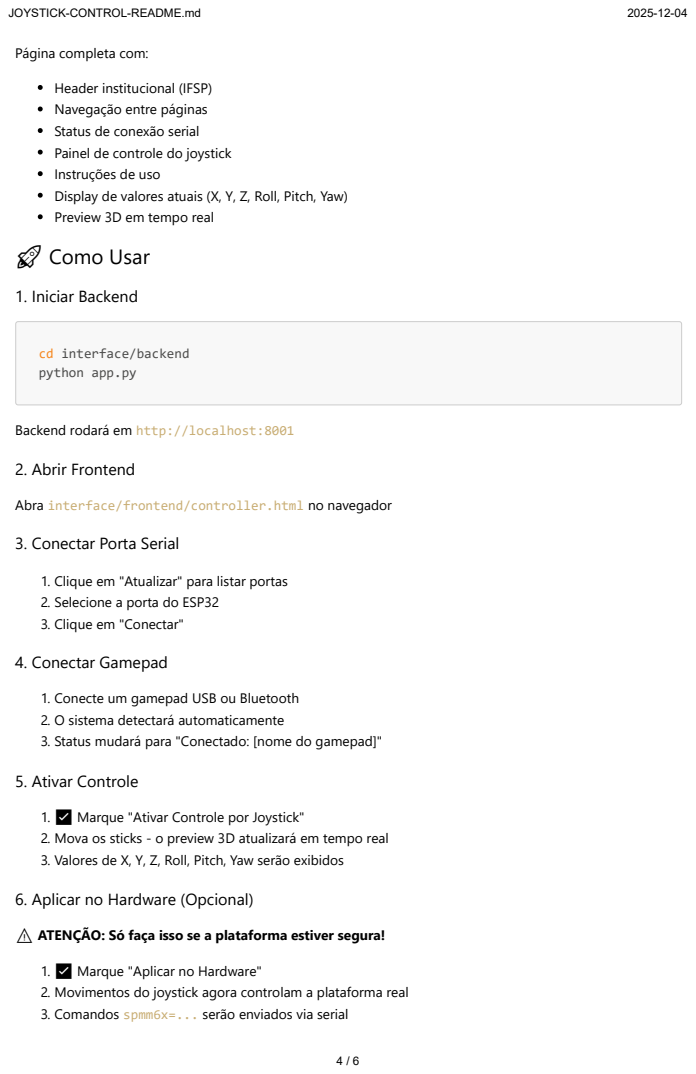
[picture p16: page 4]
1. Iniciar Backend

Página completa com:

Header institucional (IFSP)
Navegação entre páginas
Status de conexão serial
Painel de controle do joystick
Instruções de uso
Display de valores atuais (X, Y, Z, Roll, Pitch, Yaw)
Preview 3D em tempo real

cd interface/backend
python app.py

Backend rodará em http://localhost:8001
2. Abrir Frontend

Abra interface/frontend/controller.html no navegador
3. Conectar Porta Serial

1. Clique em "Atualizar" para listar portas
2. Selecione a porta do ESP32
3. Clique em "Conectar"
4. Conectar Gamepad

1. Conecte um gamepad USB ou Bluetooth
2. O sistema detectará automaticamente
3. Status mudará para "Conectado: [nome do gamepad]"
5. Ativar Controle

1. ✅ Marque "Ativar Controle por Joystick"
2. Mova os sticks - o preview 3D atualizará em tempo real
3. Valores de X, Y, Z, Roll, Pitch, Yaw serão exibidos
6. Aplicar no Hardware (Opcional)

⚠ ATENÇÃO: Só faça isso se a plataforma estiver segura!

1. ✅ Marque "Aplicar no Hardware"
2. Movimentos do joystick agora controlam a plataforma real
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

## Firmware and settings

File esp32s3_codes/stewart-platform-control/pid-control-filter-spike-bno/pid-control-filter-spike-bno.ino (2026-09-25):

#include <Arduino.h>
#include <WiFi.h>
#include <esp_now.h>

// ================== ESP-NOW ORIENTAÇÃO ==================
// Estrutura para MPU6050 (4 campos: roll, pitch, yaw, recalibra)
typedef struct {
  float roll;
  float pitch;
  float yaw;
  bool  recalibra; 
} OrientationData;

// Estrutura para BNO085 (8 campos: roll, pitch, yaw, qw, qx, qy, qz, recalibra)
typedef struct {
  float roll;
  float pitch;
  float yaw;
  float qw;
  float qx;
  float qy;
  float qz;
  bool  recalibra;
} TelemetryData;

// Valores recebidos do ESP transmissor (suporta MPU6050 ou BNO085)
volatile float oriRoll  = 0.0f;
volatile float oriPitch = 0.0f;
volatile float oriYaw   = 0.0f;
volatile float oriQw    = 1.0f;  // quaternion (padrão: identidade)
volatile float oriQx    = 0.0f;
volatile float oriQy    = 0.0f;
volatile float oriQz    = 0.0f;
volatile bool  hasQuaternions = false;  // flag indica se recebeu quaternions

uint8_t lastSenderMac[6] = {0};

void onReceive(const uint8_t *mac, const uint8_t *incomingData, int len) {
  // Detecta formato automaticamente pelo tamanho do pacote
  if (len == sizeof(OrientationData)) {
    // Formato MPU6050 (apenas ângulos)
    OrientationData tmp;
    memcpy(&tmp, incomingData, sizeof(tmp));
    oriRoll  = tmp.roll;
    oriPitch = tmp.pitch;
    oriYaw   = tmp.yaw;
    hasQuaternions = false;
    
    // salva o MAC do transmissor para enviar comandos depois
    memcpy(lastSenderMac, mac, 6);
    
  } else if (len == sizeof(TelemetryData)) {
    // Formato BNO085 (ângulos + quaternions)
    TelemetryData tmp;
    memcpy(&tmp, incomingData, sizeof(tmp));
    oriRoll  = tmp.roll;
    oriPitch = tmp.pitch;
    oriYaw   = tmp.yaw;
    oriQw    = tmp.qw;
    oriQx    = tmp.qx;
    oriQy    = tmp.qy;
    oriQz    = tmp.qz;
    hasQuaternions = true;
    
    // salva o MAC do transmissor para enviar comandos depois
    memcpy(lastSenderMac, mac, 6);
  }
}

void setupEspNowReceiver() {
  WiFi.mode(WIFI_STA);
  delay(200);

  Serial.print("ESP-NOW RX | MAC deste ESP32-S3: ");
  Serial.println(WiFi.macAddress());

  if (esp_now_init() != ESP_OK) {
    Serial.println("Erro ao iniciar ESP-NOW");
    return; // segue sem RPY
  }

  esp_now_register_recv_cb(onReceive);
  Serial.println("ESP-NOW RX pronto. Aguardando Roll/Pitch/Yaw...");
}

// ================== PINAGEM ==================
const int FB_PINS[6]   = {1, 2, 3, 4, 5, 6};   // feedback (0..3.3V)
const int PWM_PINS[6]  = {8, 18, 9, 10, 11, 12};
const int PWM_CHANS[6] = {0, 1, 2, 3, 4, 5};

struct PistonIO { int in1; int in2; };
PistonIO pistons[6] = {
  {16, 17}, {13, 14}, {35, 36}, {21, 38}, {39, 37}, {41, 42}
};

// ================== PWM (LEDC) ==================
#define PWM_FREQ 20000
#define PWM_RES  8                    // 0..255
const float MAX_PWM = 255.0f;
uint8_t MIN_PWM = 0;                  // depois pode usar >0

// ================== CONTROLE EM mm (por pistão) ==================
float Lmm[6]       = {250,250,250,250,250,250};  // curso útil (mm)
float SP_mm[6]     = {10,10,10,10,10,10};        // setpoint em mm

float Kp_mm[6] = {5.1478, 5.2, 5.2552, 5.0969, 5.4362, 5.1724};
float Ki_mm[6] = {0.8226, 0.7, 0.6391, 0.8, 1.124, 0.8593};
float Kd_mm[6] = {0,0,0,0,0,0};

float integ[6]     = {0,0,0,0,0,0};
float last_y_mm[6] = {0,0,0,0,0,0};
bool  y_init       = false;
float deadband_mm  = 0.2f;

// ===== Feedforward (zona morta / viés) por pistão =====
float U0_adv[6] = {11,17,10.5,14,14.5,12.5};     // SUBIR
float U0_ret[6] = {8,12,9.4,14.5,11.4,11.4};     // DESCER

// ===== OFFSET DE CALIBRAÇÃO (compensação de erro sistemático) =====
float offset_mm[6] = {0, 0, 0, 0, 0, 0};  // offset em mm (+2mm para compensar)

// ================== CALIBRAÇÃO (V0 / V100) ==================
float V0[6]     = {0.25,0.25,0.25,0.25,0.25,0.25};
float V100[6]   = {3.3,3.3,3.3,3.3,3.3,3.3};
bool  hasCal[6] = {true,true,true,true,true,true};

// ===== FILTRAGEM: MEDIANA-3 + ANTI-SPIKE DINÂMICO =====
constexpr int  MA_N = 1;                 // média móvel desligada
constexpr bool USE_TRIMMED_MEAN = false; // ignorado se MA_N=1

float   fbV_buf[6][MA_N];
uint8_t fbV_idx[6]   = {0,0,0,0,0,0};
uint8_t fbV_count[6] = {0,0,0,0,0,0};
float   fbV_sum[6]   = {0,0,0,0,0,0};

float guard_lastV[6] = {0,0,0,0,0,0};
bool  guard_init = false;

float fbV_raw[6]  = {0,0,0,0,0,0};
float fbV_filt[6] = {0,0,0,0,0,0};

// ===== Anti-windup (tracking) =====
const float Tt_tracking = 0.30f;
const float I_LIM       = 1000.0f;
const float T_leak      = 0.5f;

// ===== Velocidade plausível (anti-spike) =====
float vmax_mm_s = 150.0f;

// ===== Modo manual =====
int  selIdx = 0;
bool manual_retract = false;
bool manual_advance = false;
const uint8_t RETRACT_PWM = 80;
const uint8_t ADV_PWM     = 70;

// ===== CSV =====
bool csv_header_done = false;
float last_pwm_cmd[6] = {0,0,0,0,0,0};

uint32_t last_ms = 0;
String line;

// ================== Helpers ==================
static inline float clampf(float v, float lo, float hi) {
  if (v < lo) return lo;
  if (v > hi) return hi;
  return v;
}

void setDirAdvance(int i){ digitalWrite(pistons[i].in1, HIGH); digitalWrite(pistons[i].in2, LOW ); }
void setDirReturn (int i){ digitalWrite(pistons[i].in1, LOW );  digitalWrite(pistons[i].in2, HIGH); }
void setDirFree   (int i){ digitalWrite(pistons[i].in1, LOW );  digitalWrite(pistons[i].in2, LOW ); }

float readMedianV(int pin, int N=31){
  N = constrain(N, 5, 63);
  float buf[64];
  for(int i=0;i<N;i++){
    int a = analogRead(pin);
    buf[i] = a * 3.3f / 4095.0f;
    delayMicroseconds(500);
  }
  for(int i=0;i<N;i++){
    for(int j=i+1;j<N;j++){
      if(buf[j]<buf[i]){ float t=buf[i]; buf[i]=buf[j]; buf[j]=t; }
    }
  }
  return buf[N/2];
}

// Mediana de 3 leituras rápidas
inline float analogMedian3Volts(int pin) {
  int a = analogRead(pin);
  int b = analogRead(pin);
  int c = analogRead(pin);
  if (a > b) { int t=a; a=b; b=t; }
  if (b > c) { int t=b; b=c; c=t; }
  if (a > b) { int t=a; a=b; b=t; }
  int m = b;
  return m * 3.3f / 4095.0f;
}

// Média móvel (aqui MA_N=1 -> só passa o valor)
inline float ma_update(int idx, float sampleV) {
  if (fbV_count[idx] < MA_N) {
    fbV_buf[idx][fbV_idx[idx]] = sampleV;
    fbV_sum[idx] += sampleV;
    fbV_count[idx]++;
    fbV_idx[idx] = (fbV_idx[idx] + 1) % MA_N;
  } else {
    uint8_t p = fbV_idx[idx];
    float old = fbV_buf[idx][p];
    fbV_buf[idx][p] = sampleV;
    fbV_sum[idx] += (sampleV - old);
    fbV_idx[idx] = (p + 1) % MA_N;
  }

  int valid = fbV_count[idx];
  if (valid < 1) valid = 1;

  if (USE_TRIMMED_MEAN && valid >= 3) {
    int limit = (fbV_count[idx] < MA_N) ? fbV_count[idx] : MA_N;
    float s = 0.0f, vmin =  1e9f, vmax = -1e9f;
    for (int k = 0; k < limit; ++k) {
      float v = fbV_buf[idx][k];
      s += v;
      if (v < vmin) vmin = v;
      if (v > vmax) vmax = v;
    }
    if (limit > 2) return (s - vmin - vmax) / (float)(limit - 2);
  }

  return fbV_sum[idx] / (float)fbV_count[idx];
}

float voltsToMM(int i, float V){
  if (!hasCal[i]) {
    float pct = clampf((V/3.3f)*100.0f, 0.0f, 100.0f);
    return (Lmm[i]/100.0f)*pct + offset_mm[i];  // ✅ Aplica offset
  }
  float span = V100[i] - V0[i];
  if (span < 1e-3f) span = 3.3f;
  float pct = (V - V0[i]) / span * 100.0f;
  pct = clampf(pct, 0.0f, 100.0f);
  return (Lmm[i]/100.0f) * pct + offset_mm[i];  // ✅ Aplica offset
}

inline float volts_per_mm(int i){
  float span = V100[i] - V0[i];
  if (span < 1e-3f) span = 3.3f;
  if (Lmm[i] < 1e-3f) return span / 1.0f;
  return span / Lmm[i];
}

// ================== Comandos auxiliares ==================
static void apply_setpoint_all(float v_mm){
  for(int i=0;i<6;i++){
    float v = clampf(v_mm, 0.0f, Lmm[i]);
    SP_mm[i] = v;
  }
}

static void apply_gain_all(float *arr, float v){
  for(int i=0;i<6;i++) arr[i] = v;
}

static void apply_feedforward_all(float *arr, float v_abs){
  v_abs = fabs(v_abs);
  for(int i=0;i<6;i++) arr[i] = v_abs;
}

// ================== Setup ==================
void setup() {
  Serial.begin(115200);
  while (!Serial) {}

  // ADC
  analogReadResolution(12);
  for (int i = 0; i < 6; i++) {
    analogSetPinAttenuation(FB_PINS[i], ADC_11db);
  }

  // PWM
  for (int i = 0; i < 6; i++) {
    ledcSetup(PWM_CHANS[i], PWM_FREQ, PWM_RES);
    ledcAttachPin(PWM_PINS[i], PWM_CHANS[i]);
    ledcWrite(PWM_CHANS[i], 0);
  }

  // Direção
  for (int i = 0; i < 6; i++) {
    pinMode(pistons[i].in1, OUTPUT);
    pinMode(pistons[i].in2, OUTPUT);
    setDirFree(i);
  }

  last_ms = millis();
  Serial.println(F("sep=;")); // dica pro Excel

  // ESP-NOW RX (não trava o resto se falhar)
  setupEspNowReceiver();
}

// ================== Loop ==================
void loop() {
  // ===== Parser serial =====
  while (Serial.available()) {
    char c = Serial.read();
    if (c == '\r') continue;
    if (c == '\n') {
      String cmd = line; line = ""; cmd.trim();

      if (cmd.startsWith("sel=")) {
        int v = cmd.substring(4).toInt();
        if (v < 1) v = 1; if (v > 6) v = 6;
        selIdx = v - 1;

      } else if (cmd.startsWith("spmm=")) {
        float v = cmd.substring(5).toFloat();
        apply_setpoint_all(v);

      } else if (cmd.startsWith("spmm6x=")) {
        // Comando para enviar 6 setpoints de uma vez: spmm6x=v1,v2,v3,v4,v5,v6
        String values = cmd.substring(7);
        int commaPos[5];
        int count = 0;
        
        // Encontrar posições das vírgulas
        for (int i = 0; i < values.length() && count < 5; i++) {
          if (values.charAt(i) == ',') {
            commaPos[count++] = i;
          }
        }
        
        if (count == 5) {
          // Extrair os 6 valores
          float sp_values[6];
          sp_values[0] = values.substring(0, commaPos[0]).toFloat();
          sp_values[1] = values.substring(commaPos[0] + 1, commaPos[1]).toFloat();
          sp_values[2] = values.substring(commaPos[1] + 1, commaPos[2]).toFloat();
          sp_values[3] = values.substring(commaPos[2] + 1, commaPos[3]).toFloat();
          sp_values[4] = values.substring(commaPos[3] + 1, commaPos[4]).toFloat();
          sp_values[5] = values.substring(commaPos[4] + 1).toFloat();
          
          // Aplicar e clampar todos os valores
          for (int i = 0; i < 6; i++) {
            SP_mm[i] = clampf(sp_values[i], 0.0f, Lmm[i]);
          }
          
          Serial.println("OK spmm6x aplicado");
        } else {
          Serial.println("ERR spmm6x formato: spmm6x=v1,v2,v3,v4,v5,v6");
        }

      } else if (cmd.startsWith("spmm1=") || cmd.startsWith("spmm2=") || cmd.startsWith("spmm3=") ||
                 cmd.startsWith("spmm4=") || cmd.startsWith("spmm5=") || cmd.startsWith("spmm6=")) {
        int idx = cmd.charAt(4) - '1';
        float v = cmd.substring(6).toFloat();
        v = clampf(v, 0.0f, Lmm[idx]);
        SP_mm[idx] = v;

      } else if (cmd.startsWith("kpmm=")) {
        Kp_mm[selIdx] = cmd.substring(5).toFloat();

      } else if (cmd.startsWith("kimm=")) {
        Ki_mm[selIdx] = cmd.substring(5).toFloat();

      } else if (cmd.startsWith("kdmm=")) {
        Kd_mm[selIdx] = cmd.substring(5).toFloat();

      } else if (cmd.startsWith("kpall=")) {
        apply_gain_all(Kp_mm, cmd.substring(6).toFloat());

      } else if (cmd.startsWith("kiall=")) {
        apply_gain_all(Ki_mm, cmd.substring(6).toFloat());

      } else if (cmd.startsWith("kdall=")) {
        apply_gain_all(Kd_mm, cmd.substring(6).toFloat());

      } else if (cmd.startsWith("dbmm=")) {
        deadband_mm = fabs(cmd.substring(5).toFloat());

      } else if (cmd.startsWith("lmm=")) {
        float v = fabs(cmd.substring(4).toFloat());
        if (v > 1e-3f) Lmm[selIdx] = v;

      } else if (cmd.startsWith("fc=")) {
        Serial.println(F("INFO: fc= ignorado (mediana-3 + anti-spike dinamico)."));

      } else if (cmd.startsWith("minpwm=")) {
        int v = cmd.substring(7).toInt();
        MIN_PWM = (uint8_t)constrain(v, 0, 255);

      } else if (cmd.startsWith("vmaxmmps=")) {
        float v = fabs(cmd.substring(9).toFloat());
        if (v > 1.0f) vmax_mm_s = v;
        Serial.printf("OK vmax_mm_s=%.1f mm/s\n", vmax_mm_s);

      } else if (cmd.equalsIgnoreCase("zero")) {
        float v = readMedianV(FB_PINS[selIdx], 31);
        V0[selIdx] = v; hasCal[selIdx] = true;
        Serial.printf("OK ZERO[%d]=%.4f V\n", selIdx+1, v);

      } else if (cmd.startsWith("cal=")) {
        int comma = cmd.indexOf(',');
        if (comma > 0) {
          float v0   = cmd.substring(4, comma).toFloat();
          float v100 = cmd.substring(comma+1).toFloat();
          if (v100 > v0 + 0.02f) {
            V0[selIdx] = v0; V100[selIdx] = v100; hasCal[selIdx] = true;
            Serial.printf("OK CAL[%d]=V0=%.4f V, V100=%.4f V\n", selIdx+1, v0, v100);
          } else {
            Serial.println("ERR CAL span pequeno");
          }
        }

      } else if (cmd.equalsIgnoreCase("mark100")) {
        float v = readMedianV(FB_PINS[selIdx], 31);
        V100[selIdx] = v; hasCal[selIdx] = true;
        Serial.printf("OK V100[%d]=%.4f V\n", selIdx+1, v);

      } else if (cmd.equalsIgnoreCase("v?")) {
        float v = readMedianV(FB_PINS[selIdx], 31);
        float ymm = voltsToMM(selIdx, v);
        Serial.printf("V[%d]=%.4f V | Y=%.3f mm\n", selIdx+1, v, ymm);

      } else if (cmd.startsWith("u0a=")) {
        U0_adv[selIdx] = fabs(cmd.substring(4).toFloat());
        Serial.printf("OK U0_adv[%d]=%.1f\n", selIdx+1, U0_adv[selIdx]);

      } else if (cmd.startsWith("u0r=")) {
        U0_ret[selIdx] = fabs(cmd.substring(4).toFloat());
        Serial.printf("OK U0_ret[%d]=%.1f\n", selIdx+1, U0_ret[selIdx]);

      } else if (cmd.startsWith("u0aall=")) {
        apply_feedforward_all(U0_adv, cmd.substring(7).toFloat());
        Serial.println("OK U0_adv para todos");

      } else if (cmd.startsWith("u0rall=")) {
        apply_feedforward_all(U0_ret, cmd.substring(7).toFloat());
        Serial.println("OK U0_ret para todos");

      } else if (cmd.startsWith("offset=")) {
        offset_mm[selIdx] = cmd.substring(7).toFloat();
        Serial.printf("OK offset[%d]=%.3f mm\n", selIdx+1, offset_mm[selIdx]);

      } else if (cmd.startsWith("offsetall=")) {
        float val = cmd.substring(10).toFloat();
        for (int k = 0; k < 6; k++) offset_mm[k] = val;
        Serial.printf("OK offset para todos = %.3f mm\n", val);

      } else if (cmd.equalsIgnoreCase("R")) {
        manual_retract = true; manual_advance = false;

      } else if (cmd.equalsIgnoreCase("A")) {
        manual_advance = true; manual_retract = false;

      } else if (cmd.equalsIgnoreCase("OK")) {
        // Sai do modo manual e volta ao PID sem tranco: zera o integrador e
        // reinicia a derivada a partir da posição atual.
        manual_advance = false; manual_retract = false;
        for (int k = 0; k < 6; k++) {
          integ[k] = 0.0f;
          last_y_mm[k] = voltsToMM(k, fbV_filt[k]);
        }
        Serial.println("OK modo manual desligado");

      } else if (cmd.equalsIgnoreCase("recalibra")) {
        OrientationData recalibraCmd = {};
        recalibraCmd.roll = 0;
        recalibraCmd.pitch = 0;
        recalibraCmd.yaw = 0;
        recalibraCmd.recalibra = true;

        // Verifica se o peer já existe e adiciona se necessário
        esp_now_peer_info_t peerInfo;
        memset(&peerInfo, 0, sizeof(peerInfo));
        memcpy(peerInfo.peer_addr, lastSenderMac, 6);
        peerInfo.channel = 0;
        peerInfo.encrypt = false;

        if (!esp_now_is_peer_exist(lastSenderMac)) {
          if (esp_now_add_peer(&peerInfo) != ESP_OK) {
            Serial.println("ERRO: Falha ao adicionar transmissor como peer.");
            return;
          }
        }

        esp_err_t result = esp_now_send(lastSenderMac, (uint8_t*)&recalibraCmd, sizeof(recalibraCmd));
        if (result == ESP_OK) {
          Serial.println("OK: Comando de recalibragem enviado via ESP-NOW.");
        } else {
          Serial.println("ERRO: Falha ao enviar comando de recalibragem.");
        }
      }

    } else {
      line += c;
      if (line.length() > 96) line.remove(0, line.length() - 96);
    }
  }

  // ===== Laço de controle =====
  uint32_t now = millis();
  float dt = (now - last_ms) / 1000.0f;
  if (dt <= 0) dt = 1e-3f;
  last_ms = now;

  // Medidas com mediana-3 + anti-spike
  for (int i = 0; i < 6; i++) {
    float v = analogMedian3Volts(FB_PINS[i]);

    float max_dv_v = volts_per_mm(i) * vmax_mm_s * dt;
    if (!guard_init) {
      guard_lastV[i] = v;
    } else {
      float dv = v - guard_lastV[i];
      if      (dv >  max_dv_v) v = guard_lastV[i] + max_dv_v;
      else if (dv < -max_dv_v) v = guard_lastV[i] - max_dv_v;
    }
    guard_lastV[i] = v;

    fbV_raw[i]  = v;
    fbV_filt[i] = ma_update(i, v);
  }
  guard_init = true;

  if (!y_init && !manual_retract && !manual_advance) {
    for (int k = 0; k < 6; k++) {
      last_y_mm[k] = voltsToMM(k, fbV_filt[k]);
    }
    y_init = true;
  }

  // ===== Controle =====
  if (manual_retract || manual_advance) {
    for (int i = 0; i < 6; i++) {
      if (i == selIdx) {
        if (manual_retract) {
          setDirReturn(i);
          uint8_t pwm = constrain(RETRACT_PWM, 0, (int)MAX_PWM);
          ledcWrite(PWM_CHANS[i], pwm);
          last_pwm_cmd[i] = pwm;
        } else {
          setDirAdvance(i);
          uint8_t pwm = constrain(ADV_PWM, 0, (int)MAX_PWM);
          ledcWrite(PWM_CHANS[i], pwm);
          last_pwm_cmd[i] = pwm;
        }
      } else {
        setDirFree(i);
        ledcWrite(PWM_CHANS[i], 0);
        last_pwm_cmd[i] = 0;
      }
    }
  } else {
    for (int i = 0; i < 6; i++) {
      float y_mm = voltsToMM(i, fbV_filt[i]);
      float e_mm = SP_mm[i] - y_mm;

      float ydot_mmps = (y_mm - last_y_mm[i]) / dt;
      last_y_mm[i] = y_mm;

      if (fabs(e_mm) <= deadband_mm) {
        setDirFree(i);
        ledcWrite(PWM_CHANS[i], 0);
        last_pwm_cmd[i] = 0;

        if (Ki_mm[i] != 0.0f) {
          float leak = -integ[i] / T_leak;
          integ[i] += leak * dt;
        }
        continue;
      }

      float P = Kp_mm[i] * e_mm;
      float D = Kd_mm[i] * ydot_mmps;
      float I = Ki_mm[i] * integ[i];

      float pid_no_ff = P + I - D;
      float u_ff = (pid_no_ff >= 0.0f) ?  U0_adv[i] : -U0_ret[i];

      float u_unsat = pid_no_ff + u_ff;

      float u_sat = u_unsat;
      if (u_sat >  MAX_PWM) u_sat =  MAX_PWM;
      if (u_sat < -MAX_PWM) u_sat = -MAX_PWM;

      if (Ki_mm[i] != 0.0f) {
        float anti = (u_sat - u_unsat) / Tt_tracking;
        integ[i] += (e_mm + anti) * dt;
        if (integ[i] >  I_LIM) integ[i] =  I_LIM;
        if (integ[i] < -I_LIM) integ[i] = -I_LIM;
      }

      if (u_sat >= 0) setDirAdvance(i); else setDirReturn(i);

      float pwmf = fabs(u_sat);
      if (pwmf > MAX_PWM) pwmf = MAX_PWM;
      if (pwmf > 0.0f && pwmf < (float)MIN_PWM) pwmf = (float)MIN_PWM;

      uint8_t pwm = (uint8_t)roundf(pwmf);
      ledcWrite(PWM_CHANS[i], pwm);
      last_pwm_cmd[i] = pwm;
    }
  }

  // ===== Telemetria (33 ms) =====
  static uint32_t t0 = 0;
  if (millis() - t0 >= 33) {
    t0 = millis();

    if (!csv_header_done) {
      // Header dinâmico baseado no formato recebido
      if (hasQuaternions) {
        Serial.println(F("ms;SP_mm;Y1;Y2;Y3;Y4;Y5;Y6;PWM1;PWM2;PWM3;PWM4;PWM5;PWM6;Roll;Pitch;Yaw;Qw;Qx;Qy;Qz"));
      } else {
        Serial.println(F("ms;SP_mm;Y1;Y2;Y3;Y4;Y5;Y6;PWM1;PWM2;PWM3;PWM4;PWM5;PWM6;Roll;Pitch;Yaw"));
      }
      csv_header_done = true;
    }

    float y_out[6];
    for (int i = 0; i < 6; i++) {
      y_out[i] = voltsToMM(i, fbV_filt[i]);
    }

    float r = oriRoll;
    float p = oriPitch;
    float yw = oriYaw;

    if (hasQuaternions) {
      // Formato BNO085: inclui quaternions
      Serial.printf(
        "%lu;%.3f;%.3f;%.3f;%.3f;%.3f;%.3f;%.3f;"
        "%.0f;%.0f;%.0f;%.0f;%.0f;%.0f;%.2f;%.2f;%.2f;"
        "%.4f;%.4f;%.4f;%.4f\n",
        (unsigned long)now,
        SP_mm[0],
        y_out[0], y_out[1], y_out[2], y_out[3], y_out[4], y_out[5],
        last_pwm_cmd[0], last_pwm_cmd[1], last_pwm_cmd[2],
        last_pwm_cmd[3], last_pwm_cmd[4], last_pwm_cmd[5],
        r, p, yw,
        oriQw, oriQx, oriQy, oriQz
      );
    } else {
      // Formato MPU6050: apenas ângulos
      Serial.printf(
        "%lu;%.3f;%.3f;%.3f;%.3f;%.3f;%.3f;%.3f;"
        "%.0f;%.0f;%.0f;%.0f;%.0f;%.0f;%.2f;%.2f;%.2f\n",
        (unsigned long)now,
        SP_mm[0],
        y_out[0], y_out[1], y_out[2], y_out[3], y_out[4], y_out[5],
        last_pwm_cmd[0], last_pwm_cmd[1], last_pwm_cmd[2],
        last_pwm_cmd[3], last_pwm_cmd[4], last_pwm_cmd[5],
        r, p, yw
      );
    }
  }
}

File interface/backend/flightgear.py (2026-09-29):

"""FlightGear como "tela" das páginas Simulador de voo e Orientação do avião.

O backend abre o FlightGear sem física (fdm=null) com o ERJ145 na pintura do IFSP,
e o motor de cueing (cueing.py) manda a posição do voo gravado por UDP a cada
frame: o avião na tela e a plataforma andam juntos, com o backend como relógio.
A imagem volta para a página pelo MJPEG do servidor HTTP do FlightGear
(/screenshot?stream=y), repassado em /fg/stream.

Antes de abrir, check() confere cada pré-requisito e devolve o que falta com a
correção, em vez de deixar o FlightGear falhar com uma caixa de diálogo.
"""
from __future__ import annotations

import atexit
import ctypes
import os
import re
import shutil
import socket
import subprocess
import sys
import threading
import time
from dataclasses import asdict, dataclass
from pathlib import Path
from typing import Any, Callable, Dict, List, Optional

import httpx
from fastapi import APIRouter, HTTPException
from fastapi.responses import StreamingResponse
from pydantic import BaseModel

AIRCRAFT = "erj145"
AIRCRAFT_FOLDER = "Embraer-ERJ-145"
LIVERY_NAME = "Instituto Federal"
LIVERY_XML = "ifsp.xml"
LIVERY_PNG = "ifsp-flightgear-livery.png"
HTTP_PORT = int(os.getenv("FG_HTTP_PORT", "8080"))
VISUAL_PORT = int(os.getenv("FG_VISUAL_PORT", "5511"))
CHASE_VIEW = 2
MIN_FREE_MB = 4000
# sem resposta do servidor HTTP nesse tempo = travado (diálogo de erro aberto, por exemplo)
STUCK_S = 120.0

SIM_DIR = Path(__file__).resolve().parent.parent / "simulation"
ASSETS_DIR = SIM_DIR / "assets"
EXTRA_DATA_DIR = SIM_DIR / "fgdata"
SETUP_DOC = "FLIGHTGEAR-SETUP.md"

# Aplica a câmera gravada (voos v3) a cada frame, só enquanto o backend manda active = 1;
# sem ela (voos v1/v2), a câmera fica livre para quem estiver no FlightGear.
CAMERA_NASAL = """
var cam = props.globals.getNode("/stewart-visual/camera", 1);
var apply = func {
    if (!cam.getValue("active")) return;
    var v = cam.getValue("view");
    if (v != nil and getprop("/sim/current-view/view-number") != v) setprop("/sim/current-view/view-number", v);
    setprop("/sim/current-view/heading-offset-deg", cam.getValue("hdg") or 0);
    setprop("/sim/current-view/pitch-offset-deg", cam.getValue("pitch") or 0);
    var fov = cam.getValue("fov");
    if (fov != nil and fov > 1) setprop("/sim/current-view/field-of-view", fov);
    var dist = cam.getValue("dist");
    if (dist != nil and dist != 0) setprop("/sim/chase-distance-m", dist);
};
var timer = maketimer(0, apply);
timer.start();
"""


@dataclass
class CheckItem:
    id: str
    label: str
    ok: bool
    detail: str
    fix: str = ""
    severity: str = "error"  # error: impede abrir; warning: abre mesmo assim


# -------------------- localizar instalação --------------------
def _registry_installs() -> List[Dict[str, str]]:
    if sys.platform != "win32":
        return []
    import winreg

    found = []
    keys = [
        (winreg.HKEY_LOCAL_MACHINE, r"Software\Microsoft\Windows\CurrentVersion\Uninstall"),
        (winreg.HKEY_LOCAL_MACHINE, r"Software\WOW6432Node\Microsoft\Windows\CurrentVersion\Uninstall"),
        (winreg.HKEY_CURRENT_USER, r"Software\Microsoft\Windows\CurrentVersion\Uninstall"),
    ]
    for hive, path in keys:
        try:
            root = winreg.OpenKey(hive, path)
        except OSError:
            continue
        for i in range(winreg.QueryInfoKey(root)[0]):
            try:
                sub = winreg.OpenKey(root, winreg.EnumKey(root, i))
                name = winreg.QueryValueEx(sub, "DisplayName")[0]
                if "flightgear" not in str(name).lower():
                    continue
                loc = winreg.QueryValueEx(sub, "InstallLocation")[0]
                try:
                    ver = winreg.QueryValueEx(sub, "DisplayVersion")[0]
                except OSError:
                    ver = ""
                found.append({"location": loc, "version": ver})
            except OSError:
                continue
    return found


def find_fgfs() -> Optional[Path]:
    env = os.getenv("FGFS")
    if env:
        return Path(env) if Path(env).is_file() else None
    exe = "fgfs.exe" if sys.platform == "win32" else "fgfs"
    candidates = [Path(r["location"]) / "bin" / exe for r in _registry_installs() if r["location"]]
    for base in (os.getenv("ProgramFiles"), os.getenv("ProgramFiles(x86)")):
        if base:
            candidates += sorted(Path(base).glob(f"FlightGear*/bin/{exe}"), reverse=True)
    which = shutil.which("fgfs")
    if which:
        candidates.append(Path(which))
    return next((c for c in candidates if c.is_file()), None)


def fgfs_version(fgfs: Path) -> Optional[str]:
    """Versão maior.menor ("2024.1") pelo nome da pasta ou pelo registro."""
    m = re.search(r"(\d{4}\.\d+)", str(fgfs))
    if m:
        return m.group(1)
    for r in _registry_installs():
        if r["location"] and Path(r["location"]) in fgfs.parents and r["version"]:
            m = re.match(r"(\d{4}\.\d+)", r["version"])
            if m:
                return m.group(1)
    return None


def _fgdata_version(root: Path) -> Optional[str]:
    try:
        return (root / "version").read_text(encoding="utf-8").strip()
    except OSError:
        return None


def find_fgroot(version: Optional[str], fgfs: Optional[Path] = None) -> Optional[Path]:
    candidates: List[Path] = []
    if os.getenv("FG_ROOT"):
        candidates.append(Path(os.environ["FG_ROOT"]))
    home = Path.home() / "FlightGear"
    candidates += sorted(home.glob("fgdata*"), reverse=True)
    candidates += sorted((home / "Downloads").glob("fgdata*"), reverse=True)
    if fgfs:
        candidates.append(fgfs.parent.parent / "data")
    valid = [c for c in candidates if _fgdata_version(c)]
    if version:
        match = [c for c in valid if _fgdata_version(c).startswith(version)]
        if match:
            return match[0]
    return valid[0] if valid else None


def find_aircraft() -> Optional[Path]:
    roots: List[Path] = []
    for part in (os.getenv("FG_AIRCRAFT") or "").split(os.pathsep):
        if part:
            roots.append(Path(part))
    home = Path.home() / "FlightGear"
    roots += sorted((home / "Downloads" / "Aircraft").glob("*/Aircraft"), reverse=True)
    roots.append(home / "Custom Aircraft")
    for root in roots:
        for cand in (root / AIRCRAFT_FOLDER, root):
            if (cand / f"{AIRCRAFT}-set.xml").is_file():
                return cand
        if root.is_dir():
            for sub in root.iterdir():
                if (sub / f"{AIRCRAFT}-set.xml").is_file():
                    return sub
    return None
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

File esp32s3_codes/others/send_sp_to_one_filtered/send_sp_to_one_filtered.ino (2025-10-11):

#include <Arduino.h>

// ================== PINAGEM ==================
const int FB_PINS[6] = {1, 2, 3, 4, 5, 6};   // feedback (0..3.3V)
const int PWM_PINS[6]  = {18, 8, 9, 10, 11, 12};
const int PWM_CHANS[6] = {0, 1, 2, 3, 4, 5};

struct PistonIO { int in1; int in2; };
PistonIO pistons[6] = {
  {13, 14}, {16, 17}, {35, 36}, {21, 38}, {39, 37}, {41, 42}
};

// ================== PWM (LEDC) ==================
#define PWM_FREQ 20000
#define PWM_RES   8   // 0..255

// ================== CONTROLE (um por vez) ==================
int   selIdx = 0;                  // 0..5 (pistão selecionado)
float SP_pct[6] = {0};             // setpoint por pistão (%)
float Kp[6]     = {2.0,2.0,2.0,2.0,2.0,2.0};
float Ki[6]     = {0,0,0,0,0,0};
float integ[6]  = {0,0,0,0,0,0};
float deadband_pct = 0.0f;

uint32_t last_ms = 0;

// Limites
const float   MAX_PWM = 255.0f;
const uint8_t MIN_PWM = 20;
const float   INT_LIM = 400.0f;

// ===== Filtro passa-baixa (IIR 1ª ordem) =====
float fc_hz = 4.0f;                // ajustável por "fc="
bool  fb_init = false;
float fbV_raw[6], fbPct_raw[6];
float fbV_filt[6]   = {0,0,0,0,0,0};
float fbPct_filt[6] = {0,0,0,0,0,0};

// ===== Modo manual de recuo =====
bool manual_retract = false;       // true => ignora PI e mantém recuo
const uint8_t RETRACT_PWM = 60;    // PWM fixo no recuo

// CSV
bool csv_header_done = false;

// ----- util -----
static inline float clampf(float v, float lo, float hi) {
  if (v < lo) return lo;
  if (v > hi) return hi;
  return v;
}

void setDirAdvance(int i){ digitalWrite(pistons[i].in1, HIGH); digitalWrite(pistons[i].in2, LOW ); }
void setDirReturn (int i){ digitalWrite(pistons[i].in1, LOW );  digitalWrite(pistons[i].in2, HIGH); }
void setDirFree   (int i){ digitalWrite(pistons[i].in1, LOW );  digitalWrite(pistons[i].in2, LOW ); }

void freeAllExcept(int keep){
  for(int i=0;i<6;i++){
    if(i==keep) continue;
    setDirFree(i);
    ledcWrite(PWM_CHANS[i], 0);
  }
}

void setup() {
  Serial.begin(115200);
  while (!Serial) {}

  // ADC
  analogReadResolution(12);
  for (int i = 0; i < 6; i++) analogSetPinAttenuation(FB_PINS[i], ADC_11db);

  // PWM
  for (int i = 0; i < 6; i++) {
    ledcSetup(PWM_CHANS[i], PWM_FREQ, PWM_RES);
    ledcAttachPin(PWM_PINS[i], PWM_CHANS[i]);
    ledcWrite(PWM_CHANS[i], 0);
  }

  // Direção
  for (int i = 0; i < 6; i++) {
    pinMode(pistons[i].in1, OUTPUT);
    pinMode(pistons[i].in2, OUTPUT);
    setDirFree(i);
  }

  last_ms = millis();

  // Apenas dica para Excel e cabeçalho serão enviados depois no loop
  Serial.println(F("sep=;"));
}

String line;

void loop() {
  // ===== Parser (sem ecos) =====
  while (Serial.available()) {
    char c = Serial.read();
    if (c == '\r') continue;
    if (c == '\n') {
      String cmd = line; line = ""; cmd.trim();

      if (cmd.startsWith("sel=") || cmd.startsWith("SEL=")) {
        int v = cmd.substring(4).toInt();
        if (v < 1) v = 1; if (v > 6) v = 6;
        selIdx = v - 1;
        freeAllExcept(selIdx);
      } else if (cmd.startsWith("sp=") || cmd.startsWith("SP=")) {
        float v = cmd.substring(3).toFloat();
        v = clampf(v, 0.0f, 100.0f);
        SP_pct[selIdx] = v;
      } else if (cmd.startsWith("kp=") || cmd.startsWith("KP=")) {
        Kp[selIdx] = cmd.substring(3).toFloat();
      } else if (cmd.startsWith("ki=") || cmd.startsWith("KI=")) {
        Ki[selIdx] = cmd.substring(3).toFloat();
      } else if (cmd.startsWith("db=") || cmd.startsWith("DB=")) {
        deadband_pct = fabs(cmd.substring(3).toFloat());
      } else if (cmd.startsWith("fc=") || cmd.startsWith("FC=")) {
        float v = fabs(cmd.substring(3).toFloat());
        fc_hz = clampf(v, 0.1f, 50.0f);
      } else if (cmd.equalsIgnoreCase("R")) {
        manual_retract = true;
        freeAllExcept(selIdx);
      } else if (cmd.equalsIgnoreCase("ok")) {
        manual_retract = false;
        setDirFree(selIdx);
        ledcWrite(PWM_CHANS[selIdx], 0);
      }
      // (qualquer outro comando é ignorado silenciosamente)
    } else {
      line += c;
      if (line.length() > 64) line.remove(0, line.length() - 64);
    }
  }

  // ===== Laço de controle =====
  uint32_t now = millis();
  float dt = (now - last_ms) / 1000.0f;
  if (dt <= 0) dt = 1e-3f;
  last_ms = now;

  // Medidas brutas
  for (int i = 0; i < 6; i++) {
    int fbRaw = analogRead(FB_PINS[i]);          // 0..4095
    fbV_raw[i]   = fbRaw * 3.3f / 4095.0f;
    fbPct_raw[i] = clampf((fbV_raw[i] / 3.3f) * 100.0f, 0.0f, 100.0f);
  }

  // Init filtro 1ª vez
  if (!fb_init) {
    for (int i = 0; i < 6; i++) {
      fbV_filt[i]   = fbV_raw[i];
      fbPct_filt[i] = fbPct_raw[i];
    }
    fb_init = true;
  }
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

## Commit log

2025-10-11 feat: adiciona arquivos para ler os dados de feedback filtrados
2025-10-11 refactor: substitui o slider de setpoint para um valor digitável para maior precisão
2025-10-11 docs: adiciona coletas para ganho Kp=3
    [p1-3.csv, p2-3.csv, p3-3.csv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]
2025-10-11 chore: modifica pinos de acionamento e logs de serial
2025-10-15 docs: adiciona dados formatados para analise de p1 e p2
    [p1-3.xlsx, p2-3.xlsx]
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2025-10-16 docs: formatando arquivos para importacao no matlab
    [p1-3.xlsx, p2-3.xlsx, p3-3.csv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]
2025-10-18 docs: dados teste com feedforward
    [stewart_test_2025-10-17_22-18-19.csv, stewart_test_2025-10-17_22-20-46.csv, stewart_test_2025-10-17_22-25-35.csv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]
2025-10-18 chore: atualiza dados de feedforward para cada pistão
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2025-10-18 docs: dados de teste p1
    [teste.csv]
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2025-10-19 docs: adiciona dados de aquisição de todos os pistões juntos
    [sp-to-all-1-filtered.csv, sp-to-all-1.csv]
2025-10-20 feat: adiciona UI inicial do sistema de cinemática
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2025-10-20 feat: adiciona interface para enviar os ganhos de PID e setpoints para os pistões de forma individual ou em conjunto
2025-10-20 feat: adiciona Kd para o controle da planta
2025-10-22 docs: dados de teste para controle P apos identificação de ruídos
    [p1-2-2-calibrado.csv, p1-2-calibrado.csv, p1-2.csv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]
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2025-10-25 docs: novos dados para analise
    [recalibrado.csv, single_piston_2025-10-24_20-01-35.csv, single_piston_2025-10-24_20-06-58.csv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]
2025-10-27 docs: organiza os arquivos
    [p1-2-2-calibrado.csv, p1-2-calibrado.csv, p1-2.csv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]
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2025-11-01 feat: adiciona função para sempre ir a posição inicial antes de iniciar um movimento
2025-11-02 docs: adiciona dados de teste
    [anti-spike-kp5.csv, teste-anti-spike-j5.csv, teste-media-movel-j5.csv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]
2025-11-03 feat: adiciona rotina Helix e remove rotinas de lissajous e wobble precession
    [app.py]
2025-11-03 feat: adiciona funcionalidade de zoom no grafico e filtragem de dados a serem exibidos por checkbox
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2025-11-03 feat: adiciona graficos, filtros e arruma botao de parar e contagem da duracao
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2025-11-05 fix: ajusta amostragem para 30hz
    [pid-control-filter-spike-only.ino]
2025-11-05 fix: corrige implementacao do bias
    [app.py]
2025-11-08 feat: adiciona codigo para medição de angulos em xyz
2025-11-09 feat: adiciona prog para receber posiçoes com esp now
2025-11-09 feat: adiciona comando para enviar os setpoints para todos os pistões de uma vez
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2025-11-09 feat: adiciona js para pagina de rotinas movimento
2025-11-09 feat: adiciona comando para envio de SP simultaneo
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2025-11-10 refactor: move todo scripts e css para arquivo externo
2025-11-10 refactor: move toda a logica para arquivos na pasta script
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2025-11-13 feat: adiciona nova tela de controle via joystick ao menu
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2025-11-13 feat: adiciona script para funcionamento geral da pagina
2025-11-14 feat: adiciona versoes leves de motion e controller
2025-11-14 feat: adiciona quartenions
    [stewart_full_2025-11-01_22-57-33.csv, stewart_full_2025-11-01_22-58-24.csv]
2025-11-14 fix: exibiçao dos quartenions e portas COM
    [app.py, pid-control-filter-spike-bno.ino]
2025-11-14 fix: conserta erros da serial
    [app.py]
2025-11-15 fix: arruma posicao home das rotinas de movimento e ajusta valores limites do acelerometro
    [app.py]
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2025-11-16 chore: atualiza nome dos arquivos de motion e controller para accelerometer e joystick
2025-11-16 feat: adiciona funcionalidade para o botao LT e RT para controle de Z
2025-11-16 feat: adiciona script para facilitar o inicio do back e frontend
2025-11-16 fix: ajusta limites para a cinematica inversa
2025-11-16 fix: ajusta limites de cinematica
2025-11-17 fix: retorna eixos de referencia que tinham sido removidos
2025-11-18 fix: corrige erro de comentario em linha de envio de setpoint
    [app.py]
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2025-11-19 adiciona aba para o flight simulation no menu
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2025-11-20 chore: atualiza os requirements da apliação para incluir dependencias do flightgear
2025-11-23 feat: adiciona berforeunload function para prevenir simulação de continuar rodando ao sair da página
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2025-12-04 chore: reorganiza arquivos
    [stewart_full_2025-10-26_19-07-45.csv, stewart_full_2025-11-01_22-57-33.csv, stewart_full_2025-11-01_22-58-24.csv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]
2025-12-09 feat: adiciona arquivos impressao 3d
    [Tampa.stl, base-encaixe.stl, caixa-esp32-s3-tampa.STL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]
2025-12-09 feat: arquivo aviao
    [Airliner.3mf]
2026-05-20 fix: address PR review thread feedback
    Agent-Logs-Url: https://github.com/g-Miyata/PLATAFORMA_DE_STEWART/sessions/85983f60-ba5e-4fbd-8e16-d552f3f2ea1e
2026-09-25 fix: add OK command to leave manual mode in PID firmware
    [pid-control-filter-spike-bno.ino]
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2026-09-25 feat: add React web interface with 3D model, IFSP themes and accessibility
    [kardan-joint.stl]
2026-09-26 fix: widen forward kinematics height bounds in backend
    [app.py]
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2026-09-26 chore: group navigation and share motion status, tracking chart and stage helpers
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2026-09-26 feat: add flight simulator mode, theme toggle and closer camera to the exhibit page
2026-09-27 feat: validate cardan angles and leg clearance with 20% operating margin
    [app.py, calibration.py, cueing.py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]
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2026-09-27 feat: show QR code, PIN and connected phone on the mobile page
2026-09-27 feat: show the platform response on the mobile page, full-screen touch bench and QR login with PIN
2026-09-27 fix: phone reconnecting by itself with the QR PIN, touch bench not sending by default and no feedback on sent commands
2026-09-27 fix: compact mobile layout, auto-connect the simulator for a phone and optional PIN in the exhibit QR
2026-09-27 docs: the cardan joints are metal, the blue mounts are the printed part
2026-09-27 feat: wedge lab page to simulate a tilted seat for the top cardans and export printable parts
2026-09-28 fix: emergency stop hotkey listens in the capture phase so page editors cannot swallow Esc
2026-09-28 feat: side menu opens from the left edge or the menu button, with an option to pin it
2026-09-28 feat: top cardan articulated under the plate with a bolt from above, and actuator tube length from the photos
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2026-09-29 feat: demo flight with aircraft presentation, takeoff, maneuvers and landing
    The ERJ145 demo pilot now flies a left-hand traffic circuit at SBGR 27R and
    lands on the centerline (3 degree glide path, ground-track localizer, flare,
    braking), opening with a car-commercial style camera orbit that shows the
    IFSP livery while the engines start. Recordings gain the camera (format v3)
    and the FlightGear viewer replays it; the launcher defaults to noon on 27R.
